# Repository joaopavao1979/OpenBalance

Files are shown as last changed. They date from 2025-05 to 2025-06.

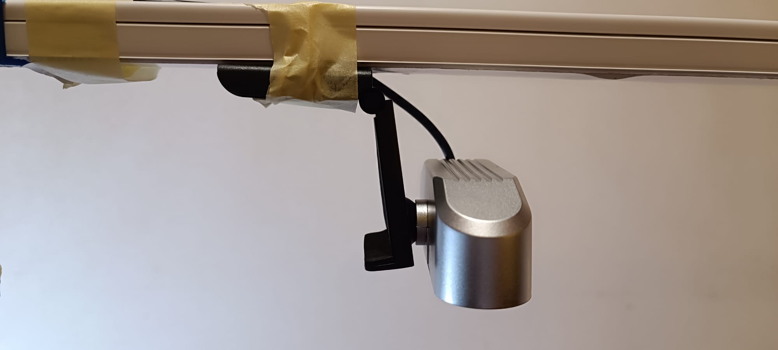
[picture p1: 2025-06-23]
02_estrutura_fisica/fotos_componentes/Eletronica_8.jpg

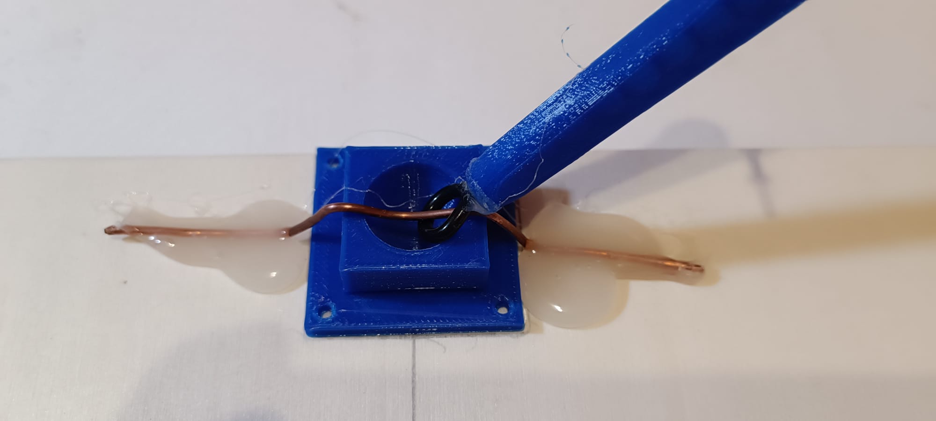
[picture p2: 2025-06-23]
02_estrutura_fisica/fotos_componentes/Estrutura_12.jpg

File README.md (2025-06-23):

# 🧠 OpenBalance – Plataforma de Equilíbrio de Bola com PID

**OpenBalance** é um projeto open source que combina visão computacional, controlo automático com Arduino e estrutura física para explorar conceitos de robótica, inteligência artificial e sistemas dinâmicos.

Desenvolvido no âmbito da pós-graduação **PRIA – Programação, Robótica e Inteligência Artificial**, o projeto tem uma forte componente pedagógica e modular, adaptável para ensino e investigação.

---

## 📂 Estrutura Principal do Projeto

| Pasta | Conteúdo |
|---|---|
| `01_documentacao` | Planeamento, cronogramas, notas e relatórios técnicos |
| `02_estrutura_fisica` | Lista de componentes, montagem física, modelos 3D |
| `03_software_arduino` | Código PID no Arduino, testes, firmware e calibração de servos |
| `04_Dashboard_OpenBalance` | Interface Python com OpenCV, sliders HSV, controlo serial e gráfico PID  |
| `05_testes_e_calibracoes` | Logs, experiências com PID (ex. Ziegler–Nichols), trajetória da bola |
| `06_recursos_pedagogicos` | Guias, fichas de aula, material didático complementar |
| `07_apresentacao` | Slides, posters e ficheiros para comunicação e defesa do projeto |
| `08_artigo_cientifico` | Artigo académico com dados, gráficos e revisão teórica |
| `09_site_github_pages` | Estrutura do site estático para publicação no GitHub Pages |

---

## 🛠️ Tecnologias Utilizadas

- **Arduino UNO** + driver **PCA9685**  
- **Servos DM996R** (13kg)  
- **Python 3.10+**  
- **CustomTkinter**, **OpenCV**, **Matplotlib**, **PySerial**, **NumPy**, **Pillow**

Instalação recomendada:

```bash
pip install customtkinter opencv-python pyserial matplotlib numpy Pillow
```

---

## 📚 Aplicações

- Ensino de sistemas de controlo e PID
- Introdução a visão computacional (HSV, deteção por cor)
- Experiências com IA e reinforcement learning
- Demonstrações práticas em sala de aula

---

## 📄 Licença

- **Código:** [MIT License](LICENSE)  
- **Conteúdos educativos:** [CC BY-NC-SA 4.0](https://creativecommons.org/licenses/by-nc-sa/4.0/)

---

## 👨‍🏫 Desenvolvido por

João Pavão – Universidade dos Açores, Pós-Graduação PRIA  
Com apoio e revisão técnica da equipa docente

---

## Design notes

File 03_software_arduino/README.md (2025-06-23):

# 📁 03_software_arduino

# 💾 Código Arduino – Projeto OpenBalance

Este repositório documenta os diferentes estágios de desenvolvimento do sistema físico OpenBalance, focado no controlo de uma plataforma de equilíbrio de bola com servomotores de alto torque e controlo PID.

O projeto evoluiu ao longo de várias abordagens e testes. Abaixo estão descritas as principais pastas e o papel de cada uma.

---

## 🗂️ Estrutura de Pastas

### 📁 `teste_motores/`
**Objetivo:** Calibração e teste individual dos servos antes da montagem do sistema.  
**Conteúdo:**  
- `calibracao_servos_v1.ino`: permite ajustar manualmente os ângulos dos servos X e Y via monitor série.  
- Comandos como `X80`, `Y120` permitem verificar os limites físicos de forma segura.

---

### 📁 `OpenBalance_Arduino_PID_testes/`
**Objetivo:** Primeiros esboços do controlo PID a correr diretamente no Arduino.  
**Conteúdo:**  
- Testes com controlo PID simples sem integração total com visão computacional.  
- Experiências com filtragem, mapeamento de ângulos e resposta dos motores.

---

### 📁 `OpenBalance_Arduino_Firmware/`
**Objetivo:** Tentativa experimental de mover o cálculo PID para o Python (dashboard), deixando o Arduino apenas a aplicar ângulos.  
**Estado:** Abordagem parcialmente funcional, mas abandonada por instabilidade na comunicação serial e atrasos.  
**Lições aprendidas:** O controlo PID é mais fiável se executado diretamente no microcontrolador.

---

### 📁 `OpenBalance_Arduino_PID/` ✅ **VERSÃO FINAL**
**Objetivo:** Implementação final e estável do sistema com controlo PID on-board.  
**Conteúdo:**  
- `OpenBalance_Arduino_PID.ino`: versão oficial final.  
- O Arduino recebe apenas os erros (X, Y) da dashboard Python via serial e calcula os ângulos de inclinação localmente usando PID.  
- Código comentado, modular e robusto.

---

## ⚙️ Hardware Utilizado

- Arduino UNO ou compatível  
- 2x servos DM996R (15 kg/cm)  
- Driver PCA9685 (PWM 16 canais)  
- Fonte regulável 6V/72W  
- Conexão com PC via USB  

---

## 🔌 Comunicação com Python

- A dashboard em Python envia erros `E,errX,errY` via porta serial.
- Comandos adicionais como `M1` e `M0` ligam/desligam os motores.
- O Arduino responde com mensagens de estado como `MOTORS_ON`.

---

## 🛠️ Bibliotecas Requeridas

- `Wire.h`  
- `Adafruit_PWMServoDriver.h`  

---

## 📌 Notas Finais

- Este repositório serve também fins pedagógicos, sendo documentado e modular.  
- A versão final (pasta `OpenBalance_Arduino_PID/`) deve ser usada como referência para integrações futuras com IA ou reforço (Q-Learning, etc.).

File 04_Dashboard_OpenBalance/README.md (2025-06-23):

# 📁 04_Dashboard_OpenBalance

# 🖥️ Dashboard Python – Projeto OpenBalance

Este repositório contém o código da interface gráfica desenvolvida em Python para o sistema físico OpenBalance, que controla uma plataforma de equilíbrio de bola em tempo real. Utiliza visão computacional, controlo PID e comunicação serial com Arduino.

---

## 🗂️ Estrutura de Pastas

### 📁 `testes_Dashboard/`
**Objetivo:** Reunião de versões experimentais e esboços da interface.  
**Conteúdo:**  
- Primeiros testes com Tkinter, sliders HSV, deteção OpenCV, e comunicação serial.  
- Algumas versões antigas ou auxiliares podem ser limpas futuramente.

---

### 📁 `Dashboard_estável/`
**Objetivo:** Versão funcional e confiável da dashboard sem gráfico de erros.  
**Características:**  
- Envio de erros `E,errX,errY` via serial.  
- Interface modular com sliders HSV, centro clicável, e controlo de motores.  
- Estável e ideal para execução contínua sem sobrecarga gráfica.

---

### 📁 `Dashboard_OpenBalance_V1.0/` ✅ **VERSÃO FINAL**
**Objetivo:** Versão final da interface com **gráfico de erro X/Y em tempo real**.  
**Ficheiro principal:** `Dashboard_OpenBalance_V1.0.py`  
**Conteúdo:**  
- Visualização OpenCV (320x240) com sobreposição de posição da bola e centro de referência.  
- Sliders ajustáveis HSV para calibração visual.  
- Controlo serial completo com comandos `M1`, `M0`, e `E,errX,errY`.  
- Interface robusta com secção para PID, estado, nivelamento e modo de seguimento.  
- Integração com `matplotlib` para abrir janela com gráfico de erro acumulado ao clicar no botão correspondente.

---

## 📦 Bibliotecas Usadas

- `customtkinter`  
- `opencv-python` (`cv2`)  
- `pyserial`  
- `Pillow`  
- `numpy`  
- `matplotlib`

Instalação recomendada:

```bash
pip install customtkinter opencv-python pyserial Pillow numpy matplotlib
```

---

## 🔌 Comunicação com Arduino

- Envio de erros via porta serial no formato: `E,errX,errY`
- Comandos de controlo:  
  - `M1` → Ativa motores  
  - `M0` → Desativa motores  
- Sincronização total com o firmware `OpenBalance_Arduino_PID.ino`

---

## 📌 Notas Finais

- A versão **`Dashboard_OpenBalance_V1.0`** deve ser usada para demonstrações e testes finais.  
- A pasta `Dashboard_estável` mantém uma alternativa leve e funcional, sem gráfico.
- As versões em `testes_Dashboard` são experimentais e poderão ser organizadas ou removidas.

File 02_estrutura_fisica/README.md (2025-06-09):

# 📁 02_estrutura_fisica

Modelos 3D (.STL e .FCStd), plantas, esquemas da estrutura da calha ou plataforma, fotos da montagem e ideias de design.

## 📦 Conteúdo

### 📁 STL/
Modelos 3D prontos para impressão:

### 📁 OBJ/
Modelos 3D 

### 📁 desenhos_tecnicos/
- Esquemas técnicos em PDF e PNG com cotas e vistas laterais
- Ideal para revisão ou produção manual

### 📁 fotos_componentes/
- Fotografias tiradas durante o processo de montagem aos componentes usados no projeto
- Ajuda visual passo a passo

### 📁 fotos_montagem/
- Fotografias tiradas durante o processo de montagem aos componentes usados no projeto
- Ajuda visual passo a passo

---

## 📋 Lista de Materiais (BOM)

| Componente | Qt. | Observações |
|---|-----|---|
| Servos MG996R | 2 | Alto torque, 180° |
| Parafuso M4x16 | 6 | Para articulações dos braços |
| Porca M4 com travamento | 6 | Evita folgas |
| Cabo jumper (M-M) | 20  | Para ligação ao Arduino |
| Base em MDF 30x42 cm | 2  | Com furações para os servos |

---

## 🪛 Instruções de Montagem

1. Imprimir os braços superior e inferior (x2 de cada)
2. Montar cada conjunto com um servo MG996R e um parafuso M4
3. Fixar os servos à base (usar `base_madeira_furos.pdf`)
4. Apoiar a plataforma sobre as 3 esferas
5. Verificar se a inclinação ocorre suavemente

---

## 🖨️ Recomendações de Impressão

- Material: PLA ou PETG
- Altura de camada: 0.2 mm
- Preenchimento: ≥30%
- Suportes: apenas se necessário nas juntas

---

## ✍️ Contribuições

Se quiseres propor melhorias nos modelos STL ou na montagem física, envia um pull request ou abre uma issue no repositório principal.

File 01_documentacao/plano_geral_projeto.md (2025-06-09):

# 🧠 Plano Geral do Projeto – OpenBalance

**Nome do Projeto:** OpenBalance  
**Autor:** João Pavão  
**Instituição:** Universidade dos Açores – PRIA  
**Período:** de maio a junho 2025  
**Versão:** 1.0

---

## 🎯 Objetivo Geral

Desenvolver um sistema open source capaz de manter uma bola em equilíbrio sobre uma plataforma inclinável, através de controlo PID e deteção da posição via visão computacional. O projeto visa integrar conhecimentos de eletrónica, programação, robótica e física, com aplicação pedagógica e científica.

---

## 📦 Componentes principais

| Componente | Função |
|---|---|
| Arduino (ex: UNO ou Leonardo) | Controlo dos servos e receção de comandos |
| 2 Servos Motores (eixo X e Y) | Ajuste da inclinação da plataforma |
| Estrutura 3D (braços + prato) | Suporte físico articulado |
| Webcam + OpenCV | Deteção da posição da bola em tempo real  |
| Python | Cálculo do PID e interface com Arduino |

---

## 🛠️ Etapas do Projeto

1. Impressão 3D e montagem dos braços articulados
2. Controlo manual dos servos via Arduino
3. Integração com PID em Python
4. Implementação de visão computacional com OpenCV
5. Criação de interface gráfica para ajuste dos parâmetros
6. Testes e calibração da resposta
7. Documentação técnica e pedagógica
8. Entrega final com vídeo, artigo e relatório

---

## 🎓 Aplicação pedagógica

O OpenBalance será usado como ferramenta de aprendizagem interdisciplinar:
- Física: sistemas de controlo, equilíbrio, movimento
- Matemática: funções PID, ângulos, vetores
- Programação: comunicação serial, tratamento de imagem
- Engenharia: design e montagem de estruturas móveis

---

## 🔓 Licenciamento

- **Código-fonte:** Licença MIT  
- **Modelos 3D, tutoriais e vídeos:** Creative Commons BY-NC-SA 4.0  

---

## 🔗 Repositórios e ligações

- GitHub do projeto: `https://github.com/joaopavao/openbalance`
- GitHub Pages (site): `https://joaopavao.github.io/openbalance`
- Pasta com ficheiros STL e documentação: `02_hardware/` e `01_documentacao/`

---

## 📝 Atualizações

- `27/05/2025`: Criação do projeto e estrutura de pastas
- `01/06/2025`: Início da montagem física
- `08/06/2025`: Finalização da construção da plataforma
- (continua...)

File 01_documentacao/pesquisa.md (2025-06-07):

# 🔍 Pesquisa Técnica – Projeto OpenBalance

**Objetivo:**  
Pesquisa inicial para o desenvolvimento de um projeto open source de **plataforma equilibradora de bola com controlo PID**, integrando eletrónica, impressão 3D e visão computacional.

---

## 🧠 Inspirações no GitHub

### 🔗 JohanLink – Ball-Balancing-PID-System
- Repositório: [https://github.com/JohanLink/Ball-Balancing-PID-System](https://github.com/JohanLink/Ball-Balancing-PID-System)
- Projeto muito bem documentado, com:
  - Visão computacional com OpenCV
  - PID controlado via Python
  - Montagem física com braços articulados
- **Referência principal para o OpenBalance**

---

### 🔗 giusenso – Ball-Balancing-PID-System
- Repositório: [https://github.com/giusenso/Ball-Balancing-PID-System](https://github.com/giusenso/Ball-Balancing-PID-System)
- Projeto alternativo com abordagem semelhante
- Útil para comparar diferentes estratégias de controlo

---

## 🧩 Modelos no Thingiverse

### 🎲 Johan Link – Ball Balancing PID System
- Projeto também publicado no Thingiverse
- Inclui ficheiros STL para braços articulados
- Impressão 3D simples, adaptável

### 🤖 BaBot – The Ball Balancing Robot (possível variação)
- Nome encontrado durante a pesquisa, necessita verificação
- Pode ser uma versão robótica com PID + rodas

---

## 📁 Notas e próximos passos

- Escolher o modelo mais simples para iniciar testes (3 DoF)
- Confirmar o uso de esfera metálica de 10 mm
- Definir os limites de rotação e altura da plataforma
- Documentar todos os testes no `diario_bordo.md`

---

## 🔗 Recursos adicionais a explorar

- Artigos científicos sobre controlo PID com Arduino
- Plataformas Stewart 3D (para versão futura com 6 DoF)
- Alternativas como HuskyLens para visão embarcada
- Projetos da comunidade OpenCV com detecção de objetos coloridos

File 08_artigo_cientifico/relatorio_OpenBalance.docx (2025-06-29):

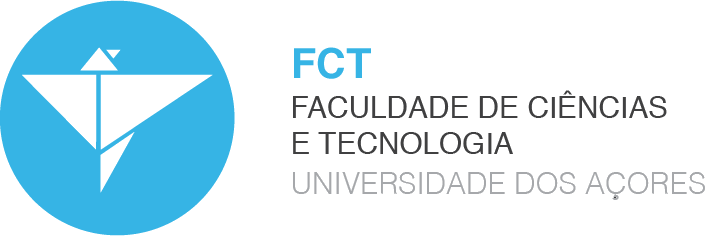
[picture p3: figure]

FACULDADE DE CIÊNCIAS E TECNOLOGIA DA UNIVERSIDADE DOS AÇORES -

CAMPUS de Ponta Delgada

COORDENAÇÃO DE CURSO DE PÓS-GRADUAÇÃO EM PROGRAMAÇÃO, ROBÓTICA E INTELIGÊNCIA ARTIFICIAL

Laboratório de Aplicações em Robótica e Aprendizagem

OpenBalance

Plataforma de Equilíbrio com Visão Computacional e Controlo PID

João Pavão

FCT – UAC

Ponta Delgada, 23 de junho de 2025

João Pavão

OpenBalance

Plataforma de Equilíbrio com Visão Computacional e Controlo PID

Relatório de atividade laboratorial para avaliação de disciplina Laboratório de Aplicações em Robótica e Aprendizagem sob orientação do Prof. José Cascalho.

FCT – UAC

Ponta Delgada, 23 de junho de 2025

RESUMO

Este relatório apresenta o desenvolvimento do projeto OpenBalance, uma plataforma robótica experimental concebida para equilibrar uma bola em tempo real, controlando dinamicamente a inclinação da sua superfície. O sistema recorre a visão computacional (OpenCV) para detetar a posição da bola e aplica algoritmos de controlo PID para mantê-la centrada. Desenvolvido no contexto da unidade curricular de Laboratório de Aplicações em Robótica e Aprendizagem (PRIA), o projeto integra conhecimentos de mecânica, eletrónica, automação e inteligência artificial aplicada. A estrutura física é composta por componentes impressos em 3D, articulações mecânicas e suportes que garantem graus de liberdade bem definidos. No domínio da eletrónica, são utilizados servomotores de alto torque, um driver PCA9685, um Arduino UNO e uma fonte de alimentação estabilizada. A deteção visual e o controlo são integrados numa interface gráfica interativa em Python, desenvolvida com CustomTkinter. Os testes realizados demonstraram estabilidade, resposta eficiente ao controlo e elevado potencial educativo, validando a proposta como recurso didático modular e reprodutível.

Palavras-chave: Visão Computacional, Controlo PID, Arduino, Mecatrónica, Interface Gráfica, Plataforma de Equilíbrio, Python

ABSTRACT

This report presents the development of OpenBalance, an experimental robotic platform designed to balance a ball in real time by dynamically controlling the inclination of its surface. The system uses computer vision (OpenCV) to detect the ball's position and applies PID control algorithms to recenter it continuously. Developed within the scope of the Laboratory of Robotics and Learning Applications (PRIA) course, the project integrates knowledge from mechanics, electronics, automation, and applied artificial intelligence. The physical structure consists of 3D-printed components, mechanical joints, and supports that define specific degrees of freedom. On the electronics side, the system uses high-torque servomotors, a PCA9685 servo driver, an Arduino UNO, and a regulated power supply. Visual detection and control are managed through an interactive graphical interface in Python, built with CustomTkinter. The conducted tests demonstrated system stability, effective response to control inputs, and strong educational potential, validating the platform as a modular and reproducible teaching tool.

Keywords: Computer Vision, PID Control, Arduino, Mechatronics, Graphical Interface, Ball-Balancing Platform, Python

1 INTRODUÇÃO

O projeto OpenBalance foi desenvolvido no contexto da unidade curricular de Laboratório de Aplicações em Robótica e Aprendizagem (PRIA), com o objetivo de demonstrar, de forma prática e interativa, os princípios do controlo automático aplicados ao equilíbrio de uma bola sobre uma superfície inclinável.

A plataforma física, com dois graus de liberdade (eixos X e Y), utiliza servomotores de alto torque controlados por um Arduino UNO e um driver PCA9685. A posição da bola é detetada em tempo real por uma webcam USB, com processamento de imagem em Python (OpenCV). Os ângulos de inclinação são definidos por um controlador PID, com parâmetros ajustáveis por uma interface gráfica desenvolvida em CustomTkinter.

Concebido com foco pedagógico e modularidade, o OpenBalance visa facilitar o ensino de robótica, visão computacional e controlo, permitindo ainda perspetivar evoluções futuras com inteligência artificial aplicada.

2 OBJETIVO

O objetivo principal do projeto é desenvolver uma plataforma robótica educativa que permita explorar conceitos de controlo PID e visão computacional em tempo real, num sistema físico acessível e reprodutível.

Objetivos específicos:

- Construir uma plataforma mecânica com dois eixos de inclinação (X/Y);
- Detetar a posição da bola por webcam e OpenCV;
- Aplicar controlo PID para manter a bola centrada;
- Desenvolver uma interface gráfica com ajuste HSV e controlo PID;
- Calibrar o sistema e otimizar o desempenho;
- Documentar o projeto e disponibilizá-lo em repositório open source;
- Explorar expansões futuras: controlo com mais atuadores, plataforma tipo Stewart, RL e sensores táteis.
3 CONTEXTO

Inserido no curso de pós-graduação em Programação, Robótica e Inteligência Artificial (PRIA), o OpenBalance é uma plataforma didática que conjuga hardware acessível e software livre para demonstrar, em tempo real, o funcionamento de sistemas de controlo. O sistema integra uma base física inclinável (PLA+contraplacado), dois servomotores DM996, um Arduino UNO com driver PCA9685 e uma webcam. A deteção da bola é feita por segmentação de cor via OpenCV, e o controlo é realizado por algoritmos PID com comunicação serial entre Python e Arduino. A interface gráfica permite controlar o sistema e ajustar parâmetros de forma intuitiva. Este projeto promove a aprendizagem prática de conceitos de robótica e automação, sendo facilmente replicável em ambientes educativos com recursos limitados.

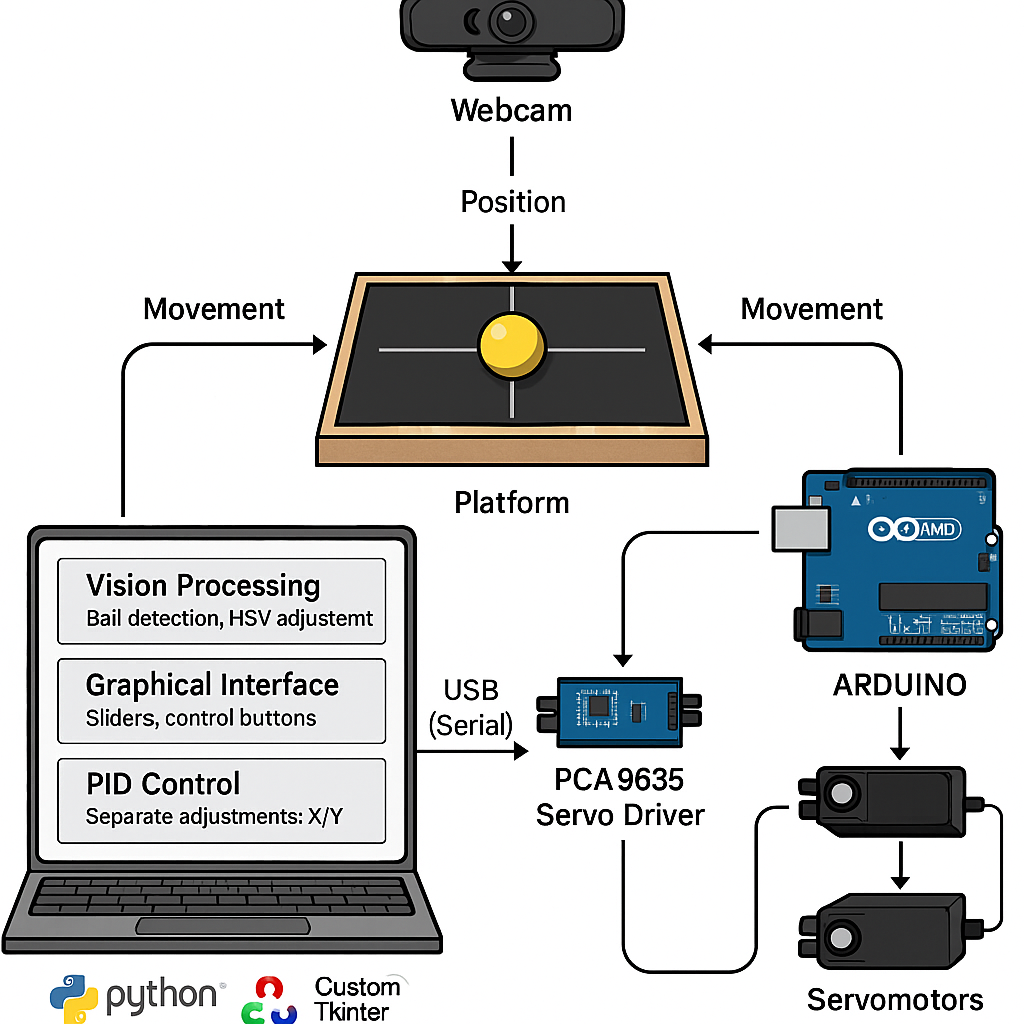
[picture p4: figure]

Figura 1 – Diagrama de arquitetura do sistema OpenBalance

4 DESENVOLVIMENTO E RESULTADOS

O projeto OpenBalance foi desenvolvido em várias fases, desde a montagem física até à implementação dos sistemas de controlo e interface. A plataforma seguiu princípios de modularidade, acessibilidade e reprodutibilidade, com recurso a componentes simples e ferramentas open source.

Estrutura física e montagem

A estrutura foi construída com base móvel em contraplacado leve e suportes articulados em PLA. Dois servomotores DM996 (15 kg·cm) montados lateralmente permitem controlar a inclinação nos eixos X e Y. A plataforma assenta sobre um pivô côncavo, garantindo estabilidade e liberdade de movimento. Encaixes tipo cavilha nos braços asseguram o alinhamento e evitam deslizamento.

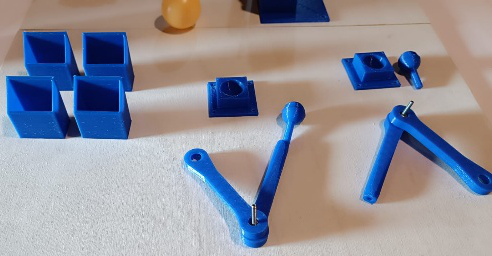
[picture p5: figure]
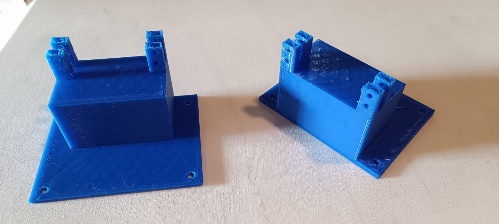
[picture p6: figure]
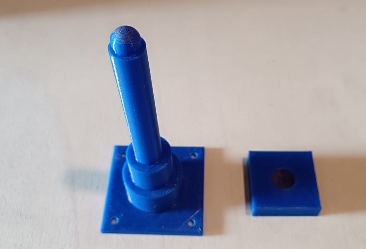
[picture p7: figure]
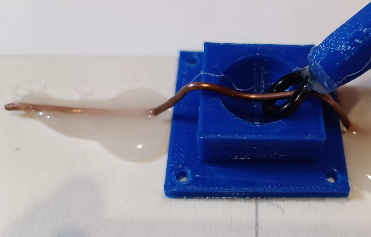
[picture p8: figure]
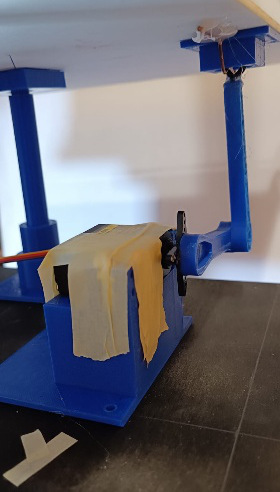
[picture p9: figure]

Figura 2 – Vários componentes que formam a estrutura da plataforma

A superfície visível da plataforma foi pintada de preto com uma cruz central (destinada ao alinhamento da webcam e a plataforma) e uma borda de madeira natural (~4 mm), otimizando o contraste visual para a deteção por visão computacional.

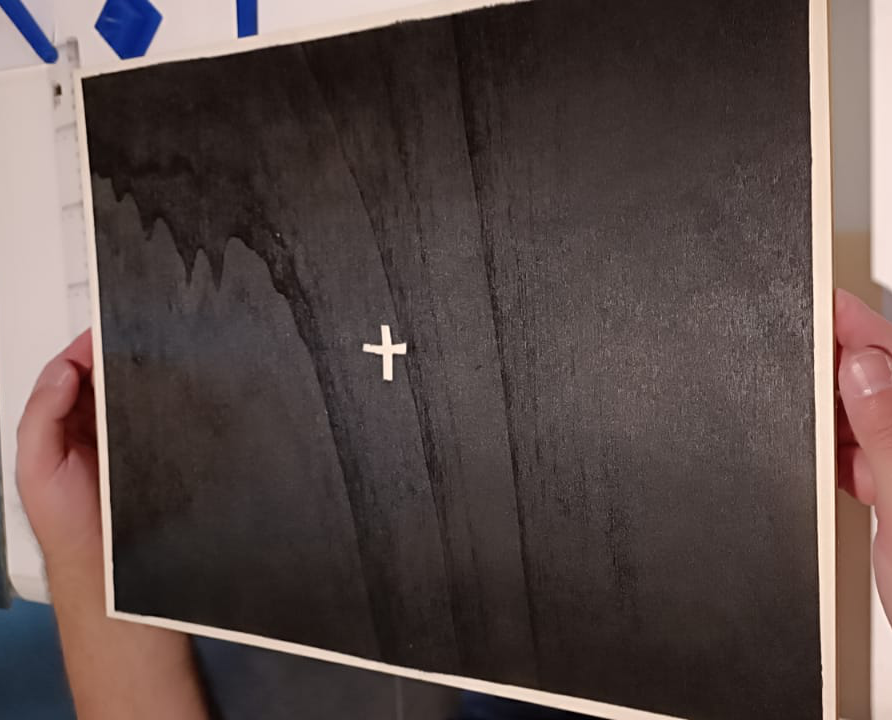
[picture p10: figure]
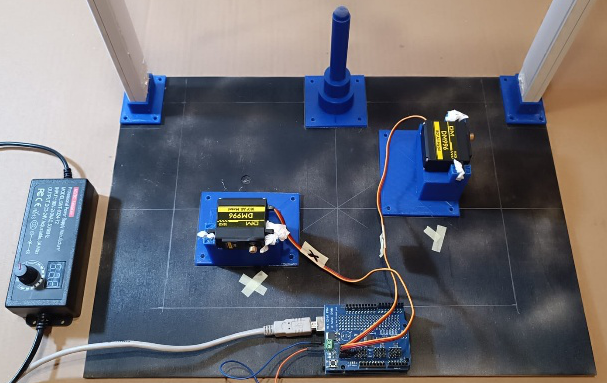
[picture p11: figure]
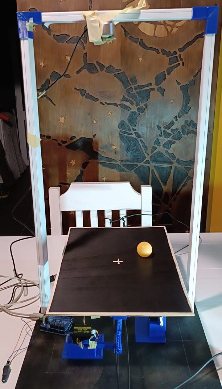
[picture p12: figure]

Figura 3 – Montagem da estrutura – etapas finais

Sistema eletrónico

O controlo dos servos é feito por um Arduino UNO ligado a um driver PCA9685 (I²C), que gera sinais PWM precisos. A alimentação é fornecida por uma fonte regulável de 6 V / 72 W, isolando o Arduino da carga. A comunicação com o PC é realizada via porta serial USB. A deteção da bola é feita por uma webcam USB montada verticalmente sobre a plataforma.

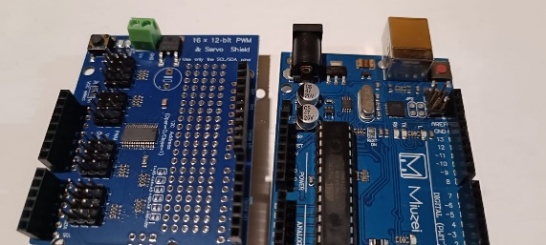
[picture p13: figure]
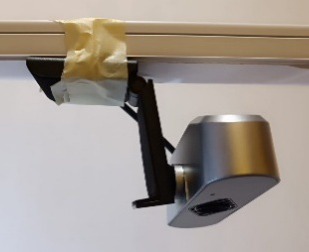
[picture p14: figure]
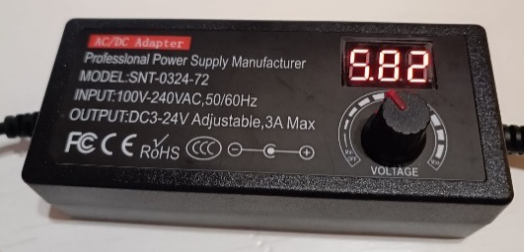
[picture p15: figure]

Driver PCA9685 e Arduino Uno | Webcam USB | Fonte regulável

Figura 4 – Vários componentes da parte eletrónica

Calibração dos servomotores

Para garantir movimentos seguros e previsíveis, foi realizada calibração manual dos servos. Cada motor foi centrado a 90°, alinhando a estrutura para obter uma superfície nivelada. Utilizando um sketch de teste, determinaram-se os limites operacionais:

• Eixo X: 80°–120°

• Eixo Y: 70°–110°

Estes valores foram inseridos no firmware, assegurando que os comandos respeitam os limites físicos.

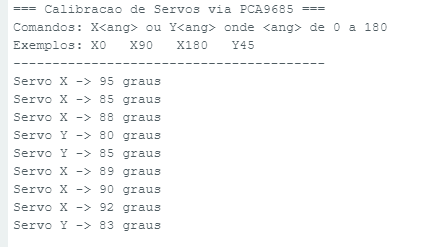
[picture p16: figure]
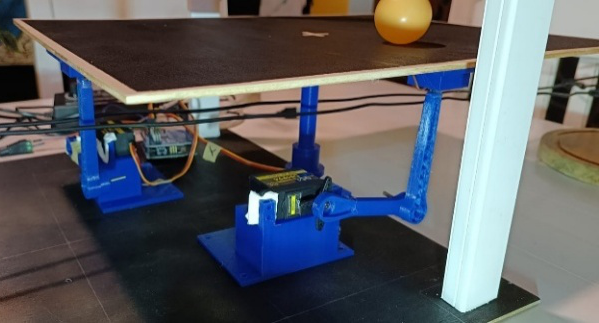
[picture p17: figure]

Calibração dos motores feita no monitor serial do Arduino IDE | Calibração dos motores de modo a permitir a plataforma nivelada

Figura 4 – Calibração manual dos servomotores

Sintonização PID com o Método de Ziegler–Nichols

A afinação do controlo PID requer definição adequada dos ganhos proporcional (Kp), integral (Ki) e derivativo (Kd). Uma abordagem empírica eficaz, mesmo sem modelo matemático, é o método de Ziegler–Nichols (ZN), amplamente utilizado.

O procedimento consiste em:

1. Desativar Ki e Kd;
2. Aumentar Kp até provocar oscilações sustentadas (→ obter Ku);
3. Medir o período de oscilação (Tu);
4. Aplicar as fórmulas empíricas para calcular os ganhos ótimos.

Tabela 1 – Fórmulas empíricas de sintonização segundo Ziegler–Nichols

Tipo de controlador | Kp | Ki | Kd
P | 0.50 × Ku | — | —
PI | 0.45 × Ku | 1.2 × Kp / Tu | —
PID | 0.60 × Ku | 2 × Kp / Tu | Kp × Tu / 8

Foram realizados testes variando Kp no eixo X, com Ki e Kd a zero e o eixo Y desativado. A análise do comportamento permitiu avaliar a sensibilidade do sistema ao ganho proporcional e orientar a introdução progressiva de Ki e Kd, com base em tentativa e erro.

Tabela 2 – Testes experimentais de controlo proporcional no eixo X

Após a afinação individual dos eixos, o controlo PID foi ativado simultaneamente. Os valores atualmente utilizados no firmware estão ilustrados na Figura 5 e servem como referência inicial, podendo ser ajustados conforme a resposta do sistema.

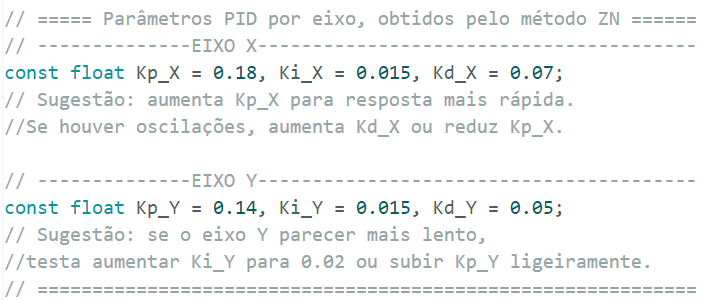
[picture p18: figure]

Figura 5 - Parâmetros PID definidos no firmware Arduino com base no método ZN

Está prevista uma futura atualização da dashboard com funcionalidade ZN, que estimará automaticamente os ganhos PID a partir do comportamento oscilatório, simplificando e acelerando o processo de afinação.

Interface gráfica e interatividade

A interface gráfica foi desenvolvida em CustomTkinter, com arquitetura modular e tema escuro. É composta por três áreas principais:

- Painel HSV – sliders para ajuste em tempo real da segmentação por cor, com presets e visualização da máscara;
- Área de vídeo – exibe a imagem processada com a bola detetada, erro X/Y e marcadores de referência;
- Controlo do sistema – botões para gerir motores, seguimento automático, redefinir o centro e escolher a porta COM.

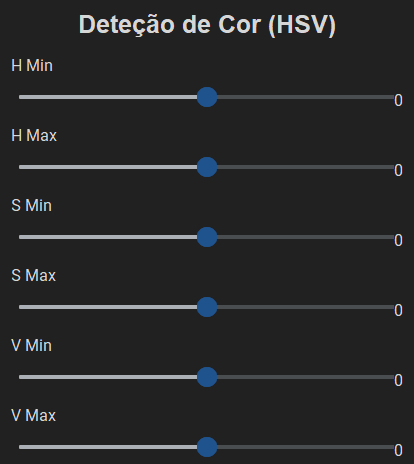
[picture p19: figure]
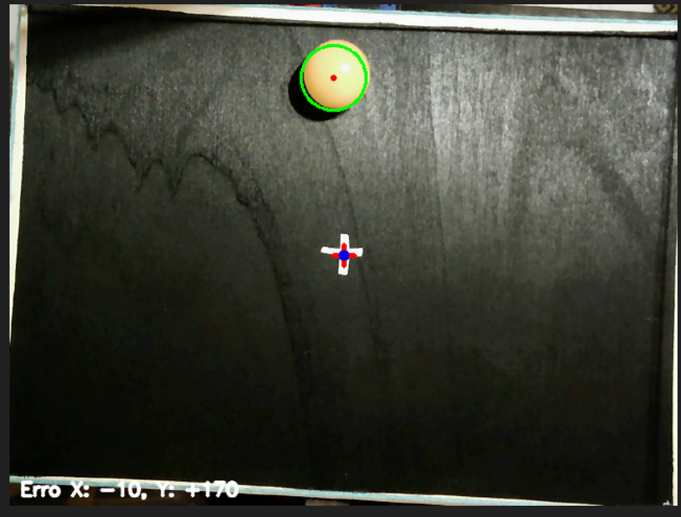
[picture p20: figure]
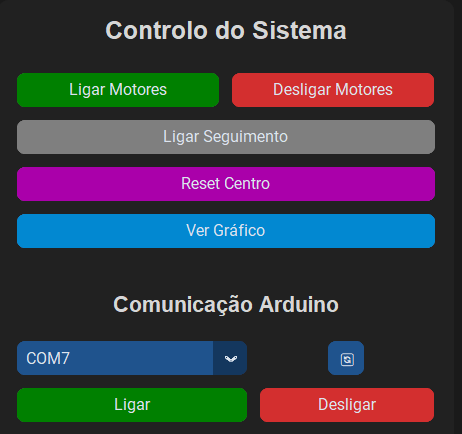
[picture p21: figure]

Painel HSV | Área de Visualização | Controlo do Sistema

Figura 6 – Várias partes constituintes da interface gráfica

A versão 1.0 da dashboard inclui:

• Janela popup com gráficos em tempo real (Erro X/Y vs Tempo e Trajetória Y vs X);

• Resolução de vídeo 640×480, equilibrando qualidade e desempenho;

• Barra de estado com mensagens de sistema e erros;

• Botão "Reset Centro", que redefine visualmente o ponto de convergência da bola com um clique, facilitando os testes.

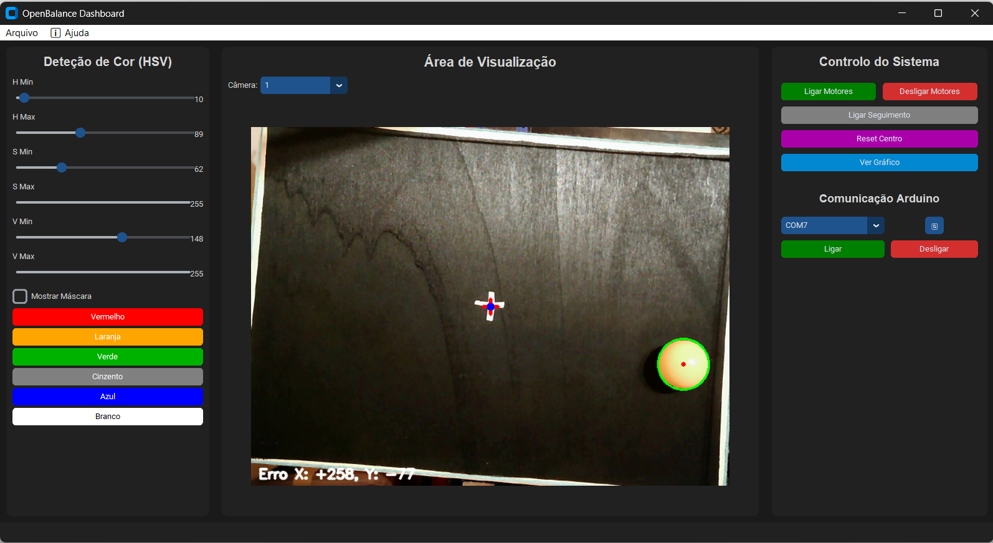
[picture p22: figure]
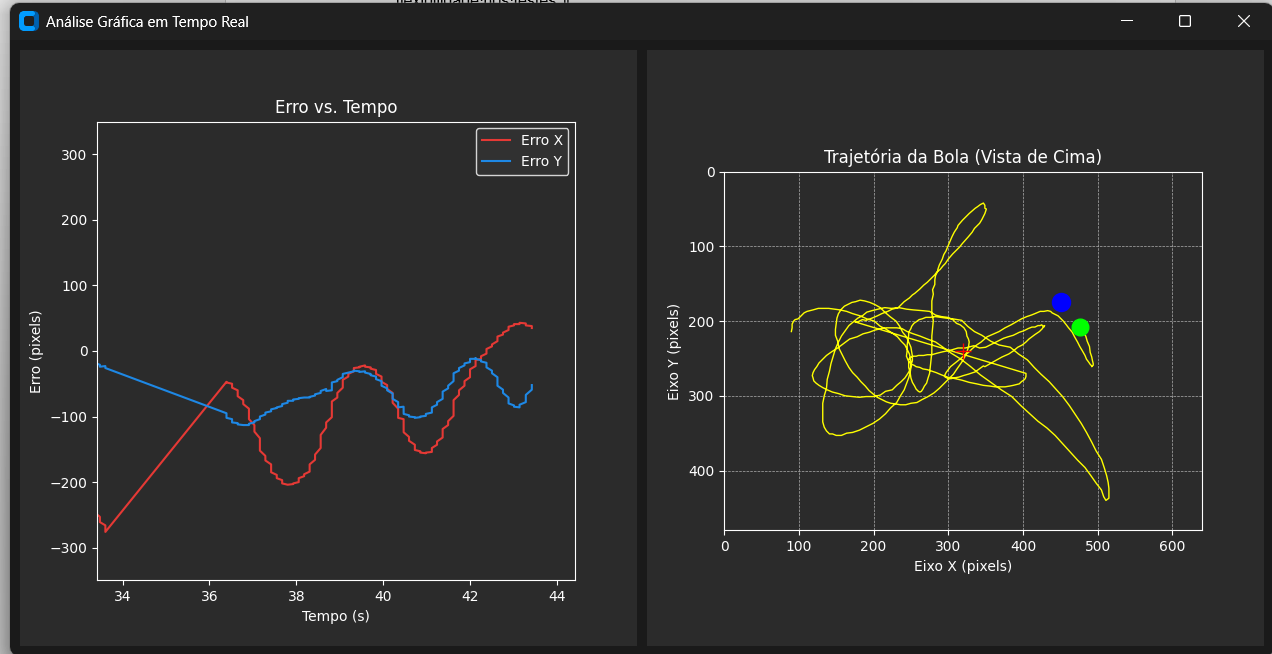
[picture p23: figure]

Figura 7 - Interface gráfica da dashboard OpenBalance (v1.0) e Análise gráfica em tempo real

A aplicação permite guardar/carregar configurações HSV (JSON), alternar entre câmaras e aceder a menus de ajuda. Foi concebida como ferramenta robusta, pedagógica e extensível para afinação e demonstrações educativas.

Testes e resultados preliminares

Os testes realizados em ambiente real revelaram:

• Deteção visual eficaz com bolas contrastantes (ex: laranja), a 20–25 FPS sob luz difusa;

• Estabilização confiável após perturbações, com PID ajustado por Ziegler–Nichols;

• Resposta física precisa dos servos, com limites que evitam colisões;

• Afinação assistida, facilitada pela visualização em tempo real dos efeitos dos parâmetros.

O projeto está documentado num repositório GitHub com vídeos, presets e imagens:

https://github.com/joaopavao1979/OpenBalance

Procedimento futuro para Aplicação de Algoritmos de Otimização e Aprendizagem

Para integrar algoritmos de otimização e aprendizagem no OpenBalance, propõe-se um procedimento experimental com aplicação direta no sistema físico, útil para afinar controladores PID ou treinar agentes de Reinforcement Learning (RL) com base em dados reais.

1. Definir parâmetros e intervalos:

Selecionar os parâmetros a otimizar (ex: Kp, Ki, Kd ou políticas de ação), definindo limites seguros.

2. Preparar o sistema:

Garantir estabilidade e segurança (ex: proteção contra quedas). A comunicação Arduino–Python deve aceitar envio dinâmico de parâmetros, com visão ativa.

3. Estruturar episódios experimentais:

Cada episódio inclui:

- Envio de parâmetros;
- Execução por tempo fixo ou até falha;
- Cálculo de métricas (erro, tempo até falha, número de colisões);
- Armazenamento dos dados.

4. Critérios de término:

Encerrar o episódio ao detetar colisão ou atingir o tempo-limite.

5. Aplicar o algoritmo:

Possíveis abordagens:

- Hill Climbing – variações incrementais com seleção por desempenho;
- Q-Learning – construção de política discreta com base em recompensas;
- Outros …

6. Registo e visualização:

Guardar os resultados e gerar gráficos de evolução e comparação de estratégias.

7. Validação final:

Testar a solução considerada ótima em vários episódios para avaliar robustez e consistência. Este procedimento fornece uma base sólida para aplicação de algoritmos de controlo inteligente em robótica, permitindo explorar IA de forma prática.

5 CONCLUSÃO

O projeto OpenBalance permitiu aplicar, de forma prática e integrada, os conhecimentos adquiridos na unidade curricular de Laboratório de Aplicações em Robótica e Aprendizagem (PRIA). Através da construção de uma plataforma física capaz de equilibrar uma bola com base em visão computacional e controlo PID, foram explorados conceitos fundamentais de automação, eletrónica e programação, perspetivando-se futuramente a integração de inteligência artificial aplicada.

Privilegiando simplicidade, modularidade e reprodutibilidade, a plataforma utilizou componentes acessíveis e software open source. A interface gráfica desenvolvida em Python com OpenCV e CustomTkinter, aliada à comunicação com o Arduino, revelou-se uma solução eficaz para controlo e afinação em tempo real, com clara mais-valia para contextos didáticos.

Do ponto de vista pedagógico, o sistema demonstrou elevado potencial como recurso de ensino em áreas como controlo automático, visão computacional e robótica, favorecendo a aprendizagem ativa e a ligação entre teoria e prática.

No entanto, o projeto enfrentou desafios importantes. A calibração física da plataforma revelou-se mais complexa do que o esperado, sendo difícil realizar a afinação Ziegler–Nichols por eixo e combinar ambos de forma linear. Também surgiram limitações na estrutura mecânica, como a fragilidade dos braços e uniões da plataforma, que exigiram reforços improvisados com cola quente, fita adesiva e ajustes manuais. A montagem exigiu várias tentativas e erros, especialmente ao alinhar os ângulos neutros dos servos.

Apesar destas dificuldades, a experiência foi profundamente formativa, destacando a importância da prototipagem, da integração entre hardware e software e da capacidade de adaptação perante constrangimentos reais. Salienta-se ainda o valor da cultura maker, que deve ser mais promovida nos clubes de robótica, incentivando a experimentação prática, a criatividade e a resolução colaborativa de problemas.

Perspetivas Futuras

A experiência adquirida com o OpenBalance abre várias possibilidades de evolução:

• Expansão para sistemas com mais graus de liberdade;

• Inclusão de braços articulados capazes de interagir ativamente com a bola, promovendo comportamentos orientados a objetivos;

• Integração de algoritmos de aprendizagem por reforço, permitindo adaptação progressiva baseada na experiência;

• Substituição da visão computacional por superfícies táteis ou resistivas, melhorando a latência e fiabilidade da deteção;

• Uso de câmaras de maior resolução e processamento embarcado com Raspberry Pi, aumentando a autonomia e portabilidade.

A nível pessoal e académico, o projeto reforçou a importância da experimentação, da integração entre hardware e software e do potencial das ferramentas open source em contextos educativos. No futuro, pretendo continuar a explorar formas de tornar sistemas como o OpenBalance mais autónomos, interativos e adaptativos, integrando aprendizagem automática e novas modalidades sensoriais.

BIBLIOGRAFIA

### Referências Bibliográficas – Artigos Científicos

- Pradeepa, S. C., Abhijith, N., Amoghavarsha, S. G., Kiran, C. N., & Niranjana Jois, H. C. (2022). Ball balancing PID system using image processing. International Journal for Research in Applied Science & Engineering Technology (IJRASET), 10(VIII), 397–406. https://doi.org/10.22214/ijraset.2022.46190
- Frank, A. H., & Tjernström, M. (2019). Construction and theoretical study of a ball balancing platform: Limitations when stabilizing dynamic systems through implementation of automatic control theory (Bachelor’s thesis, KTH Royal Institute of Technology). TRITA ITM-EX 2019:35. https://www.kth.se
- Maldonado, A., Bueno, C., Loza, D., & Ibarra, A. (s.d.). Design, construction and implementation of Stewart Platform – Control of rolling ball on platform through artificial vision. Universidad de las Fuerzas Armadas – ESPE.
- Ziegler, J. G., & Nichols, N. B. (1942). Optimum settings for automatic controllers. Transactions of the ASME, 64, 759–768. Disponível em http://www.driedger.ca

Controlo e Automação

- Ogata, K. (2010). Modern Control Engineering (5th ed.). Prentice Hall.
- Dorf, R. C., & Bishop, R. H. (2017). Modern Control Systems (13th ed.). Pearson.
- Nise, N. S. (2020). Control Systems Engineering (8th ed.). Wiley.

Robótica Educacional e Arduino

- Blum, J. (2013). Exploring Arduino: Tools and Techniques for Engineering Wizardry. Wiley.
- Monk, S. (2016). Programming Arduino: Getting Started with Sketches (2nd ed.). McGraw-Hill Education.

Python, OpenCV e Interfaces Gráficas

- Beyeler, M. (2017). Machine Learning for OpenCV. Packt Publishing.
- Laganière, R. (2014). OpenCV 3 Computer Vision Application Programming Cookbook. Packt Publishing.
- Chen, J. (2023). Learn OpenCV with Python by Examples.
- Harrison, M. (2017). Tkinter GUI Programming by Example. Packt Publishing.

Webgrafia

- GitHub – JohanLink:

https://github.com/JohanLink/Ball-Balancing-PID-System

- GitHub – giusenso:

https://github.com/giusenso/Ball-Balancing-PID-System

- Thingiverse – Ball Balancing PID Robot:

https://www.thingiverse.com/thing:4457405

- Documentação oficial do OpenCV:

https://docs.opencv.org

- Adafruit – 16-Channel PWM Servo Driver (PCA9685):

https://learn.adafruit.com/16-channel-pwm-servo-driver

- CustomTkinter – GUI Moderna para Python:

https://github.com/TomSchimansky/CustomTkinter

- Control Engineering – PID Control Explained:

https://www.controleng.com/articles/pid-control-explained

- Maker Guides – Curso de Controlo PID com Arduino:

https://www.makerguides.com/arduino-pid-controller

Utilização de Inteligência Artificial como Ferramenta de Apoio

Durante a elaboração deste projeto, foram utilizadas ferramentas de Inteligência Artificial generativa como ChatGPT (OpenAI), Gemini AI (Google AI Studio) e Grok (xAI), com o objetivo de apoiar a estruturação do relatório, esclarecer dúvidas técnicas e sugerir soluções programáticas. Estas ferramentas serviram como complemento ao trabalho do autor, que foi responsável pela interpretação, implementação e validação prática de todas as soluções propostas.

Exemplos de prompts utilizados:

- “Cria uma estrutura de relatório técnico para um projeto de controlo PID com visão computacional.”
- “Explica como calibrar servos com Arduino usando PCA9685.”
- “Como implementar controlo PID em Python com comunicação serial para Arduino?”
- “Sugere uma interface gráfica com CustomTkinter para controlo PID e HSV em tempo real.”
- “Descreve os passos de testes e validação de um sistema que equilibra uma bola com feedback visual.”
- “Adiciona perspetivas futuras para uma plataforma de controlo com múltiplos braços e IA.”
- “Faz uma reflexão final para relatório técnico com foco pedagógico e open-source.”

Estas interações fazem parte do processo de engenharia de prompts, uma prática recente e relevante na utilização eficaz de sistemas de IA, que foi conscientemente explorada como ferramenta de aprendizagem e prototipagem rápida.

Ferramentas de IA utilizadas:

- ChatGPT – OpenAI:https://chat.openai.com
- Gemini AI Studio – Google:https://studio.google.com
- Grok – xAI:https://x.com

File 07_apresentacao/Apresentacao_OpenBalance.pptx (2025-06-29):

## OpenBalance Plataforma de Equilíbrio com Controlo PID e Visão Computacional

https://github.com/joaopavao1979/OpenBalance
PRIA – Laboratório de Aplicações em Robótica e Aprendizagem
Autor: João Pavão
Data: 27 de junho de 2025

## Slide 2

A IDEIA

Plataforma que equilibra uma bola automaticamente
Usa câmara para detetar a posição da bola
Controla a inclinação com dois servos (X e Y)
Algoritmo PID ajusta os ângulos em tempo real
Projeto educativo e open-source

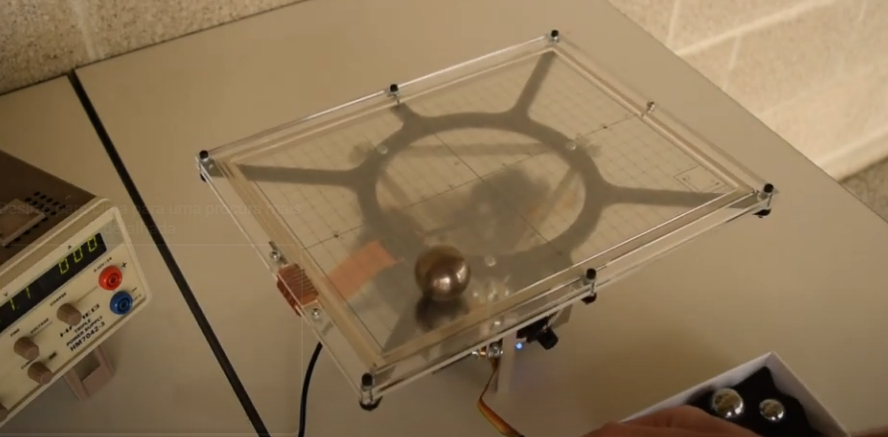
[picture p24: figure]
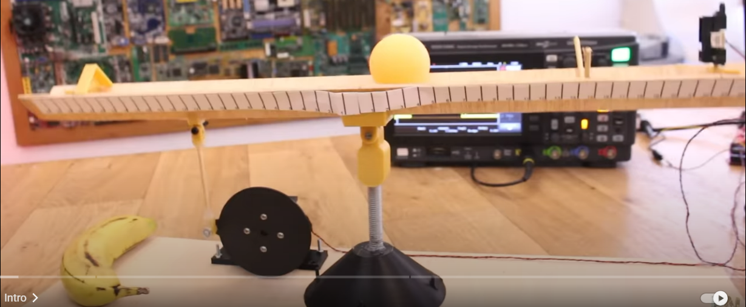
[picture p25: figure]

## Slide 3

Estrutura Física

Plataforma em contraplacado pintado de preto
Cruz branca no centro + borda de madeira visível
Dois braços 3D com suporte para servos
Pivô central com base côncava
Webcam fixa numa estrutura superior

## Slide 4

Estrutura Física

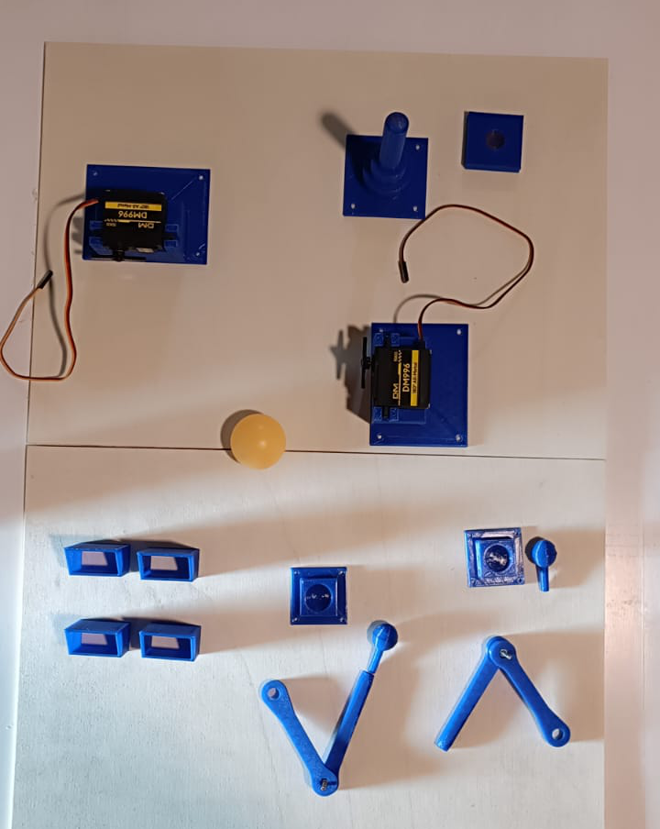
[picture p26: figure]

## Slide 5

Estrutura Física


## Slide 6

Eletrónica

Arduino UNO para controlo central
PCA9685 para controlar servos com precisão
2 servos DM996 (15 kg·cm)
Fonte de alimentação 6V / 72W
Webcam USB ligada ao PC

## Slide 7

Eletrónica


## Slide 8

Programação

Python (no PC):
OpenCV para visão
PID para controlo
Interface gráfica com sliders (CustomTkinter)
Envio de comandos para o Arduino

Arduino:
Recebe comandos via serial
Controla servos com PCA9685
Aplica limites de segurança definidos na calibração

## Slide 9

Programação

Python (no PC):

Arduino:


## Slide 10

Calibração dos servomotores


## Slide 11

Calibração PID


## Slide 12

Calibração PID


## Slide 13

Calibração PID


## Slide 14

Calibração PID


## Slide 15

Calibração Ziegler-Nichols – calibração ZN


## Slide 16

E se o sistema aprendesse sozinho?

"Será possível substituir a afinação manual por aprendizagem automática em tempo real, com base no comportamento observado?"

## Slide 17

Integração futura de algoritmos inteligentes

Aplicação direta em ambiente físico (sem simulação)
Ajuste automático de PID ou aprendizagem de estratégias com RL
Processo baseado em episódios, métricas reais e validação iterativa


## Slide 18

Comparação: Gymnasium vs OpenBalance


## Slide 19

Etapas para otimização/aprendizagem

Definir parâmetros a otimizar (ex: Kp, Ki, Kd)
Preparar sistema e segurança
Executar episódios com métricas
→ erro médio, tempo até falha, nº de colisões
Aplicar algoritmo de otimização
Hill Climbing, Q-Learning, etc
Avaliar e validar robustez final

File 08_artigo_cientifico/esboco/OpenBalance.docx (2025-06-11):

Universidade dos Açores

Pós-Graduação em Programação, Robótica e Inteligência Artificial (PRIA)

Relatório de Projeto Experimental

OpenBalance – Plataforma de Equilíbrio com Visão Computacional e Controlo PID

Autor: João Pavão

Docente: Prof. José Cascalho

Ponta Delgada, 14 de junho de 2025

# Resumo

Este relatório apresenta o desenvolvimento do projeto OpenBalance, uma plataforma robótica capaz de equilibrar uma bola através do controlo da inclinação da sua superfície. O sistema recorre a visão computacional para localizar a bola em tempo real e aplica algoritmos de controlo PID para manter a sua posição centrada. Desenvolvido no contexto da unidade curricular de Laboratório de Aplicações em Robótica e Aprendizagem (PRIA), este projeto combina conceitos de automação, controlo e inteligência artificial aplicada, com uma forte vertente pedagógica e open-source. Utiliza componentes como Arduino, servomotores, driver PCA9685 e uma webcam USB, integrados por uma interface gráfica construída em Python com CustomTkinter.

Palavras-chave: Visão Computacional, Controlo PID, Arduino, Robótica Educacional, OpenCV, CustomTkinter

# Índice

## 1. Introdução

O presente relatório documenta o desenvolvimento do projeto OpenBalance, uma plataforma robótica experimental concebida no âmbito da unidade curricular de Laboratório de Aplicações em Robótica e Aprendizagem (PRIA) da Universidade dos Açores. O sistema tem como principal objetivo demonstrar, de forma visual e interativa, os fundamentos do controlo automático aplicados a um problema clássico: o equilíbrio dinâmico de uma bola sobre uma superfície inclinável.

A ideia central consiste em permitir que uma bola se mantenha centrada numa plataforma bidimensional, cuja inclinação é controlada por dois servomotores, um em cada eixo (X e Y). A posição da bola é monitorizada em tempo real através de uma webcam USB, com processamento de imagem realizado em Python utilizando a biblioteca OpenCV. A decisão sobre os ângulos de inclinação é determinada por algoritmos de controlo PID (Proporcional–Integral–Derivativo), ajustáveis através de uma interface gráfica interativa desenvolvida com CustomTkinter.

O OpenBalance não é apenas uma implementação técnica; constitui também uma ferramenta pedagógica e de código aberto, pensada para facilitar o ensino e a aprendizagem de conceitos fundamentais de automação, controlo, robótica e visão computacional. A modularidade do sistema permite que seja facilmente replicado, adaptado e expandido, por exemplo para sistemas de maior complexidade como plataformas de Stewart (6 graus de liberdade).

Ao longo deste relatório serão apresentados os objetivos do projeto, os componentes utilizados, a estrutura de hardware e software desenvolvida, bem como as estratégias de calibração e os resultados obtidos. Será ainda feita uma reflexão sobre as potencialidades educativas do projeto e as perspetivas futuras para a sua evolução.

## 2. Objetivos

O projeto OpenBalance tem como objetivo principal o desenvolvimento de uma plataforma robótica educativa capaz de demonstrar o funcionamento de sistemas de controlo em tempo real, com particular enfoque no controlo PID e na visão computacional. Esta plataforma serve como um modelo físico interativo para o estudo de sistemas dinâmicos, permitindo a aplicação prática de conceitos abordados na unidade curricular de Laboratório de Aplicações em Robótica e Aprendizagem.

Objetivos específicos:

- Construir uma plataforma mecânica funcional que permita a inclinação controlada de uma superfície em dois eixos (X e Y), com servomotores de precisão;
- Integrar um sistema de aquisição de imagem em tempo real, utilizando uma webcam USB e a biblioteca OpenCV para deteção da posição de uma bola sobre a plataforma;
- Implementar algoritmos de controlo PID para estabilizar a posição da bola no centro da superfície, ajustando dinamicamente os ângulos dos servos;
- Desenvolver uma interface gráfica interativa (Dashboard) em Python com CustomTkinter, permitindo ao utilizador ajustar os parâmetros do controlo PID e da deteção de cor (HSV), bem como visualizar o vídeo e interagir com o sistema;
- Testar e calibrar o sistema físico e os algoritmos de controlo, otimizando o desempenho para diferentes condições;
- Documentar o processo de desenvolvimento, desde a conceção mecânica até à implementação do software, promovendo uma abordagem pedagógica, acessível e reprodutível;
- Explorar possibilidades de expansão futura, com destaque para:
  - A evolução da plataforma para sistemas com três ou mais braços de controlo, permitindo não só o equilíbrio passivo da bola mas também ações proativas e direcionadas sobre o movimento da mesma;
  - A conceção de um sistema tipo Stewart com seis graus de liberdade, oferecendo um campo de controlo tridimensional e potencial para simulações avançadas;
  - A incorporação de comportamentos mais interativos, como a capacidade de “bater” ou impulsionar a bola intencionalmente para zonas-alvo, baseando-se em inputs visuais e algoritmos de decisão;
  - A integração com algoritmos de inteligência artificial, nomeadamente aprendizagem por reforço, para que o sistema aprenda estratégias ótimas de controlo ou interação a partir da experiência acumulada.

Estas perspetivas futuras posicionam o OpenBalance como uma plataforma aberta, escalável e reprodutível, com potencial para projetos de investigação, ensino avançado e demonstrações interativas em contextos científicos ou educativos. Todo o código-fonte, esquemas eletrónicos, ficheiros de impressão 3D e documentação estão a ser organizados e publicados num repositório público no GitHub, promovendo a colaboração, a partilha de boas práticas em robótica educativa e a reutilização do projeto em contextos escolares, académicos ou pessoais. O projeto será disponibilizado sob licença open source, incentivando a sua adaptação, evolução e integração em futuras iniciativas.

## 3. Materiais e Montagem Física

### 3.1 Materiais Gerais

Bola leve (ex: esférica de pingue-pongue ou borracha macia)

Contraplacado fino (base da plataforma móvel)

Parafusos, porcas e anilhas M3 e M4

Cabos Dupont, terminais e fita dupla face

Tinta preta fosca (para contraste visual da plataforma)

Calha técnica em PVC (para suporte da webcam)

### 3.2 Eletrónica

Microcontrolador: Arduino UNO (ou compatível)

Módulo controlador de servos: PCA9685 (16 canais, I²C)

Servomotores: 2x DM996 (15 kg·cm, compatíveis com 6 V)

Fonte de alimentação: Fonte regulável 6 V / 72 W (com bornes)

Webcam USB: Câmera genérica HD (fixada em estrutura superior)

Cablagem adicional: fios, conectores macho-fêmea, ficha de alimentação

### 3.3 Estrutura Física e Impressão 3D

Braços articulados (x2): Impressos em PLA, com suporte para servos e encaixes de fixação à base

Suportes laterais: Estrutura rígida para montagem vertical dos servos

Pivô central: Elemento circular ou cónico, também em PLA, que permite rotação e estabilidade da plataforma

Encaixes tipo cavilha: Integrados nos braços para evitar deslizamento lateral

Plataforma móvel: Contraplacado pintado de preto com cruz central branca e borda natural visível (~4 mm) para facilitar a deteção por visão computacional

### 3.4 Montagem e Infraestrutura

Os braços 3D foram aparafusados diretamente aos servos, que por sua vez foram fixados às paredes laterais da base.

A plataforma repousa livremente sobre os braços, encaixando nos pinos e no pivô central para estabilidade e liberdade de movimento.

A webcam foi montada sobre uma calha técnica superior, garantindo uma visão perpendicular e estável de toda a área da plataforma.

O circuito foi montado numa breadboard lateral com ligações ao Arduino e à alimentação externa.

A fonte de alimentação foi cuidadosamente ajustada para fornecer 6 V estáveis e proteger os servos de sobrecargas.

## 4. Arquitetura do Sistema

O funcionamento do projeto OpenBalance assenta na integração de diversos subsistemas — deteção visual, controlo PID e interface gráfica — que comunicam entre si de forma coordenada. A arquitetura do sistema foi concebida para funcionar em tempo real, garantindo a resposta rápida necessária à estabilização da bola na plataforma.

### 4.1 Deteção Visual com OpenCV

A deteção da posição da bola é feita com recurso a uma webcam USB fixada verticalmente sobre a plataforma. A imagem captada é processada em Python, usando a biblioteca OpenCV, com o objetivo de localizar a bola em cada frame.

O processo é realizado da seguinte forma:

- Captura de imagem: Utiliza-se o cv2.VideoCapture() para capturar imagens da webcam em tempo real.
- Conversão de cores: A imagem é convertida do espaço BGR para HSV (cv2.cvtColor) para permitir uma segmentação mais robusta da cor da bola, mesmo com variações de luz.
- Filtragem por intervalo HSV: Aplicam-se máscaras (cv2.inRange) com base em valores ajustáveis via interface, permitindo identificar apenas a cor da bola.
- Tratamento morfológico: Usa-se erosão e dilatação para remover ruído e obter uma forma limpa.
- Localização do centroide: Com cv2.findContours e cv2.moments, calcula-se o centro (x, y) da bola, que representa a sua posição relativa na imagem.
- Escalonamento para coordenadas da plataforma: A posição em píxeis é convertida para uma escala proporcional à plataforma, usada no controlo PID.

A plataforma é pintada de preto com uma cruz branca no centro e uma borda natural de madeira visível (~4 mm), o que favorece o contraste visual e melhora a fiabilidade da deteção. Este sistema oferece uma taxa de atualização suficiente para aplicações de controlo em tempo real (≥ 20 FPS em máquinas comuns).

### 4.2 Controlo PID e Comando da Plataforma

A posição da bola em relação ao centro da plataforma é usada como erro de entrada para dois controladores PID, um para cada eixo (X e Y).

O algoritmo calcula a correção necessária para devolver a bola ao centro, ajustando os ângulos dos servos.

- PID em Python: O cálculo do PID é realizado diretamente em Python, com fórmulas discretas para as componentes proporcional, integral e derivativa:

onde e(t) é a distância da bola ao centro nos eixos X ou Y.

- Conversão para ângulo de servo: O sinal de controlo resultante do PID é mapeado para um intervalo de ângulos seguros (por exemplo, 80º a 120º para X e 70º a 110º para Y).
- Envio de comandos ao Arduino: Os valores de ângulo são enviados via comunicação serial para o Arduino, que aciona os servos através do driver PCA9685.
- Arduino como interface de controlo:
  - Recebe comandos via porta serial (ex: "X105Y95").
  - Usa a biblioteca Adafruit PWM Servo Driver para controlar os servos em PWM de 16 canais.
  - Aplica os ângulos com limites de segurança definidos durante a fase de calibração.

Esta separação de responsabilidades permite que o controlo lógico e visual seja feito no PC, enquanto o controlo físico é delegado ao microcontrolador, aumentando a robustez e modularidade do sistema.

### 4.3 Interface Gráfica em Python

A interface gráfica foi desenvolvida com a biblioteca CustomTkinter, que permite criar GUIs modernas com tema escuro, sliders estilizados e separação por painéis.

A interface está dividida em três áreas principais:

- Painel HSV (deteção da bola):
  - Sliders para ajuste em tempo real dos limites de Hue, Saturation e Value;
  - Vista prévia da máscara HSV gerada, permitindo afinar a segmentação;
  - Botão para guardar os valores de HSV em ficheiro CSV.
- Painel PID (controlo da plataforma):
  - Sliders para ajuste dos parâmetros Kp, Ki e Kd para cada eixo;
  - Visualização numérica dos valores;
  - Possibilidade de reiniciar os acumuladores do PID;
  - Gravação de presets em CSV para teste posterior.
- Painel de vídeo e controlo:
  - Visualização em tempo real do vídeo processado com sobreposição da posição da bola;
  - Botões para iniciar/pausar seguimento, ligar motores e selecionar a porta serial do Arduino;
  - Deteção automática das portas COM disponíveis.

Toda a lógica de controlo, comunicação e processamento está integrada na interface, o que facilita a interação com o sistema e a experimentação com diferentes configurações. A interface foi projetada para ser pedagógica, intuitiva e extensível.

## 5. Calibração dos Serrvomotores

A calibração dos servomotores é um passo crítico para garantir o bom funcionamento da plataforma móvel do OpenBalance, pois define os limites físicos de inclinação e assegura que os movimentos da plataforma correspondem corretamente aos comandos enviados pelo sistema de controlo PID.

Procedimento Inicial de Calibração

Antes de iniciar o controlo automático, foi necessário determinar os ângulos mínimos e máximos seguros para cada servo (eixo X e Y), de modo a evitar esforços excessivos, vibrações ou colisões com a estrutura.

1. Posição neutra (90°):
  - Cada servo foi inicialmente posicionado a 90°, correspondente à posição horizontal da plataforma.
  - A montagem dos braços 3D foi feita com a plataforma nivelada nesta posição, garantindo simetria.
2. Limites físicos:
  - Através de testes manuais e observação, foram definidos intervalos seguros para cada servo:
    - Eixo X: aproximadamente 80° a 120°
    - Eixo Y: aproximadamente 70° a 110°
  - Estes valores dependem da montagem física, da folga mecânica e da rigidez dos materiais.
3. Estabilização da estrutura:
  - Para garantir precisão, foram adicionados encaixes tipo cavilha nos braços 3D e uma base côncava no pivô central, evitando folgas laterais.
  - A plataforma foi construída de modo a não ser muito lisa, aumentando a aderência sem prejudicar o deslizamento suave da bola.

Implementação da Calibração no Código

A calibração foi incorporada diretamente no código Arduino, responsável por acionar os servos via o módulo PCA9685:

- Foram definidos limites máximos e mínimos para cada servo, de modo que os valores recebidos do computador fossem automaticamente restringidos dentro da faixa segura;
- Foi criado um modo de teste manual na dashboard, permitindo enviar ângulos específicos e observar o movimento da plataforma em tempo real;
- A lógica de controlo no Arduino converte os ângulos em pulsos PWM compatíveis com os servos DM996, respeitando o mapeamento definido na calibração.

Exemplo de pseudocódigo para mapeamento:

if (anguloX > 120) anguloX = 120;

if (anguloX < 80) anguloX = 80;

Validação com Feedback Visual

Durante a calibração, a posição da plataforma foi monitorizada com a webcam instalada na parte superior. Esta abordagem permitiu:

- Ajustar a inclinação máxima sem sair do campo de visão da câmara;
- Garantir que a plataforma se mantinha estável em repouso (90°);
- Verificar que os movimentos em X e Y não causavam oscilações indesejadas ou contacto com os limites físicos.

A calibração adequada dos servos garante não só a segurança mecânica do sistema, mas também o bom desempenho do controlo PID, pois permite respostas consistentes e previsíveis aos comandos de correção enviados pelo algoritmo.

## 6. Testes e Resultados Preliminares

Após a montagem física e implementação do software, foi realizada uma bateria completa de testes para validar o comportamento do sistema OpenBalance em condições reais de operação. Os testes envolveram a deteção visual da bola, o controlo PID em tempo real e a resposta física da plataforma acionada por servomotores, com resultados globalmente positivos.

Deteção Visual com OpenCV

A deteção da bola revelou-se estável e precisa após o ajuste adequado dos parâmetros HSV na interface gráfica:

- Foram testadas bolas de várias cores e materiais, sendo as de cor laranja mate e amarela as que ofereceram melhor contraste sobre a plataforma preta;
- A máscara HSV gerada por OpenCV foi eficaz na maioria das condições de iluminação, especialmente sob luz difusa e estável;
- A presença de uma cruz branca central e uma borda natural visível (~4 mm) permitiu localizar claramente o centro e os limites da plataforma, melhorando a calibração espacial;
- A taxa de atualização de vídeo situou-se entre 20 e 25 FPS, suficiente para aplicações em controlo dinâmico.

Desempenho do Controlo PID

Com os valores de PID ajustados via sliders, o sistema demonstrou boa capacidade de manter a bola próxima do centro da plataforma:

- A componente proporcional K_p teve maior influência no retorno rápido da bola ao centro;
- O termo derivativo K_d suavizou significativamente os movimentos, reduzindo oscilações;
- O uso controlado da componente integral K_i ajudou a corrigir desvios persistentes sem causar instabilidade;
- A bola foi capaz de recuperar de pequenas perturbações e manteve-se estável em repouso, validando a eficácia do controlo PID implementado.

Comportamento Físico da Plataforma

A estrutura da plataforma e os servomotores apresentaram desempenho satisfatório:

- Os limites de inclinação previamente definidos (X: 80°–120°, Y: 70°–110°) mostraram-se adequados, evitando impactos ou movimentos bruscos;
- Os servos DM996 responderam de forma consistente, com precisão e força suficiente para inclinar suavemente a superfície;
- A plataforma foi nivelada com sucesso, e a bola manteve-se centrada durante longos períodos de teste;
- A webcam montada na calha superior permitiu uma visão clara e estável de toda a superfície da plataforma.

Registo e Otimização

Todos os testes foram devidamente registados:

- Foram guardados presets de valores PID e HSV em ficheiros CSV para reutilização;
- A interface gráfica demonstrou ser um apoio essencial para afinação em tempo real;
- O código e dados obtidos foram integrados no repositório GitHub, garantindo transparência e partilha do conhecimento;
- Vídeos e capturas de ecrã documentaram o desempenho do sistema e serão utilizados na apresentação final.

Com os testes realizados, conclui-se que o OpenBalance cumpre com sucesso os objetivos definidos: demonstrar o funcionamento de um sistema de controlo em tempo real com feedback visual, utilizando uma abordagem acessível, modular e educativa.

## 7. Conclusão e Perspetivas Futuras

O desenvolvimento do projeto OpenBalance permitiu integrar, de forma prática e aplicada, os conhecimentos adquiridos ao longo da unidade curricular de Laboratório de Aplicações em Robótica e Aprendizagem (PRIA). Através da construção de uma plataforma física capaz de equilibrar uma bola com base em visão computacional e controlo PID, foi possível explorar conceitos fundamentais de automação, eletrónica, programação e inteligência artificial aplicada.

A abordagem adotada foi orientada para a simplicidade, modularidade e reprodutibilidade, utilizando componentes acessíveis e software open-source. A integração de uma interface gráfica interativa permitiu não só afinar os parâmetros de controlo, mas também tornar o sistema mais pedagógico e visualmente compreensível. A utilização de Python com OpenCV e CustomTkinter, aliada à comunicação serial com o Arduino, mostrou ser uma solução eficaz e flexível para sistemas robóticos educativos.

Do ponto de vista pedagógico, o projeto destacou-se como uma ferramenta de elevada aplicabilidade no ensino de controlo automático, visão computacional e robótica, podendo ser facilmente replicado em contexto escolar ou universitário. A capacidade de visualizar em tempo real a resposta de um sistema PID perante estímulos externos reforça a ligação entre teoria e prática, promovendo a aprendizagem ativa.

Dito pelo ChatGPT:

Aqui está a Secção 7 — Conclusão e Perspetivas Futuras, com foco na reflexão crítica, contributos pedagógicos e caminhos de evolução do projeto OpenBalance. Está estruturada para fechar o relatório de forma forte e articulada com os objetivos da pós-graduação PRIA.

7. Conclusão e Perspetivas Futuras

O desenvolvimento do projeto OpenBalance permitiu integrar, de forma prática e aplicada, os conhecimentos adquiridos ao longo da unidade curricular de Laboratório de Aplicações em Robótica e Aprendizagem (PRIA). Através da construção de uma plataforma física capaz de equilibrar uma bola com base em visão computacional e controlo PID, foi possível explorar conceitos fundamentais de automação, eletrónica, programação e inteligência artificial aplicada.

A abordagem adotada foi orientada para a simplicidade, modularidade e reprodutibilidade, utilizando componentes acessíveis e software open-source. A integração de uma interface gráfica interativa permitiu não só afinar os parâmetros de controlo, mas também tornar o sistema mais pedagógico e visualmente compreensível. A utilização de Python com OpenCV e CustomTkinter, aliada à comunicação serial com o Arduino, mostrou ser uma solução eficaz e flexível para sistemas robóticos educativos.

Do ponto de vista pedagógico, o projeto destacou-se como uma ferramenta de elevada aplicabilidade no ensino de controlo automático, visão computacional e robótica, podendo ser facilmente replicado em contexto escolar ou universitário. A capacidade de visualizar em tempo real a resposta de um sistema PID perante estímulos externos reforça a ligação entre teoria e prática, promovendo a aprendizagem ativa.

Perspetivas Futuras

Tendo por base a experiência adquirida, identificam-se várias possibilidades de evolução do projeto:

- Expansão para uma plataforma com mais graus de liberdade, como uma estrutura tipo Stewart (6 DOF), permitindo simulações complexas em 3D;
- Adição de braços articulados com capacidade de interação ativa com a bola, incluindo movimentos como empurrar ou redirecionar a trajetória — abrindo portas a sistemas com objetivos dinâmicos, como "jogar" com a bola;
- Integração de algoritmos de inteligência artificial, como aprendizagem por reforço, permitindo que o sistema aprenda estratégias de controlo através de tentativa e erro, otimizando automaticamente os ganhos PID ou desenvolvendo comportamentos mais sofisticados;
- Uso de câmaras de maior resolução e computação embarcada com Raspberry Pi, permitindo processamento autónomo e maior portabilidade;
- Aplicação em contextos competitivos ou demonstrativos, como feiras de ciência ou o AzoresBot, onde o sistema pode ser apresentado de forma interativa ao público.

Em suma, o OpenBalance posiciona-se como um projeto com elevado valor educativo, passível de expansão em múltiplas direções — desde aplicações pedagógicas básicas até desafios de investigação avançada. O seu caráter open-source e a documentação completa disponibilizada no GitHub garantem a continuidade, partilha e evolução por parte de outros alunos, docentes ou entusiastas da robótica.

## 8. Bibliografia e Recursos

### 8.1 Bibliografia

Controlo e Automação

- Ogata, K. (2010). Modern Control Engineering (5th ed.). Prentice Hall.
- Dorf, R. C., & Bishop, R. H. (2017). Modern Control Systems (13th ed.). Pearson.
- Nise, N. S. (2020). Control Systems Engineering (8th ed.). Wiley.

Robótica Educacional e Arduino

- Blum, J. (2013). Exploring Arduino: Tools and Techniques for Engineering Wizardry. Wiley.
- Monk, S. (2016). Programming Arduino: Getting Started with Sketches (2nd ed.). McGraw-Hill Education.

Python, OpenCV e Interfaces Gráficas

- Beyeler, M. (2017). Machine Learning for OpenCV. Packt Publishing.
- Laganière, R. (2014). OpenCV 3 Computer Vision Application Programming Cookbook. Packt Publishing.
- Chen, J. (2023). Learn OpenCV with Python by Examples.
- Harrison, M. (2017). Tkinter GUI Programming by Example. Packt Publishing.

### 8.2 Webgrafia

GitHub — JohanLink:

https://github.com/JohanLink/Ball-Balancing-PID-System

GitHub — giusenso:

https://github.com/giusenso/Ball-Balancing-PID-System

Thingiverse – Ball Balancing PID Robot:

https://www.thingiverse.com/thing:4457405

Documentação OpenCV:

https://docs.opencv.org

Biblioteca Adafruit PWM Servo Driver (PCA9685):

https://learn.adafruit.com/16-channel-pwm-servo-driver

CustomTkinter – GUI Moderna para Python:

https://github.com/TomSchimansky/CustomTkinter

Introdução ao Controlo PID (PID Explained):

https://www.controleng.com/articles/pid-control-explained

Curso de Controlo PID com Arduino (Maker):

https://www.makerguides.com/arduino-pid-controller

### 8.3 Prompts utilizados (ChatGPT/OpenAI)

Durante o processo de desenvolvimento e documentação, foram utilizados vários prompts para obter apoio técnico, estrutural e criativo, incluindo:

- “Cria uma estrutura de relatório técnico para um projeto de controlo PID com visão computacional.”
- “Explica como calibrar servos com Arduino usando PCA9685.”
- “Como implementar controlo PID em Python com comunicação serial para Arduino?”
- “Sugere uma interface gráfica com CustomTkinter para controlo PID e HSV em tempo real.”
- “Descreve os passos de testes e validação de um sistema que equilibra uma bola com feedback visual.”
- “Adiciona perspetivas futuras para uma plataforma de controlo com múltiplos braços e IA.”
- “Faz uma reflexão final para relatório técnico com foco pedagógico e open-source.”

OpenBalance página 2 de 10

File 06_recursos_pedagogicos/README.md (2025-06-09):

# 📁 06_recursos_pedagogicos

Fichas práticas, planos de aula, guias para professores e sugestões de exploração interdisciplinar (robótica, física, IA, visão computacional).

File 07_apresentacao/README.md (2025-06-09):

# 📁 07_apresentacao

Slides, posters, vídeos e outros materiais para apresentação do projeto no PRIA, escolas, eventos ou feiras de ciência.

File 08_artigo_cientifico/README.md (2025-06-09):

# 📁 08_artigo_cientifico

Manuscrito científico e relatório técnico. Contém texto académico, bibliografia, figuras e dados experimentais para submissão PRIA.

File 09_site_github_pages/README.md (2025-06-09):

# 📁 09_site_github_pages

Estrutura para publicação do projeto como site no GitHub Pages. Inclui `index.md`, tutoriais, galeria de imagens e contactos.

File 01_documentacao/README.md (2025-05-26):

# 📁 01_documentacao

Esta pasta contém o planeamento do projeto, objetivos, cronogramas, e anotações pedagógicas relacionadas com a disciplina de Laboratório de Robótica.

Inclui também análise de projetos semelhantes e reflexões ligadas ao PRIA.

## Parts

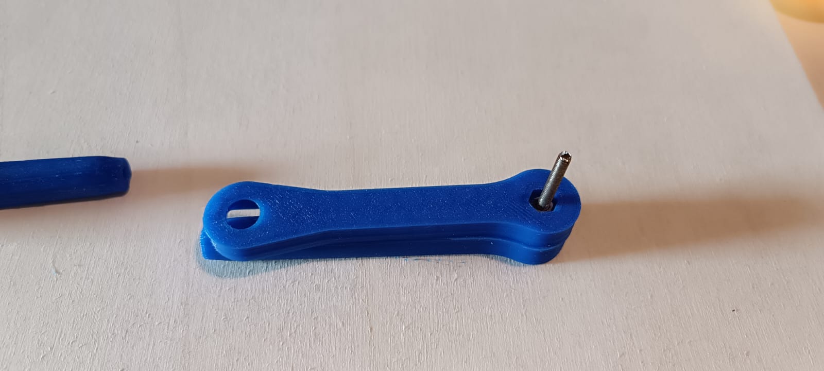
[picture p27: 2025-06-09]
02_estrutura_fisica/fotos_componentes/Mecanica_14.jpg

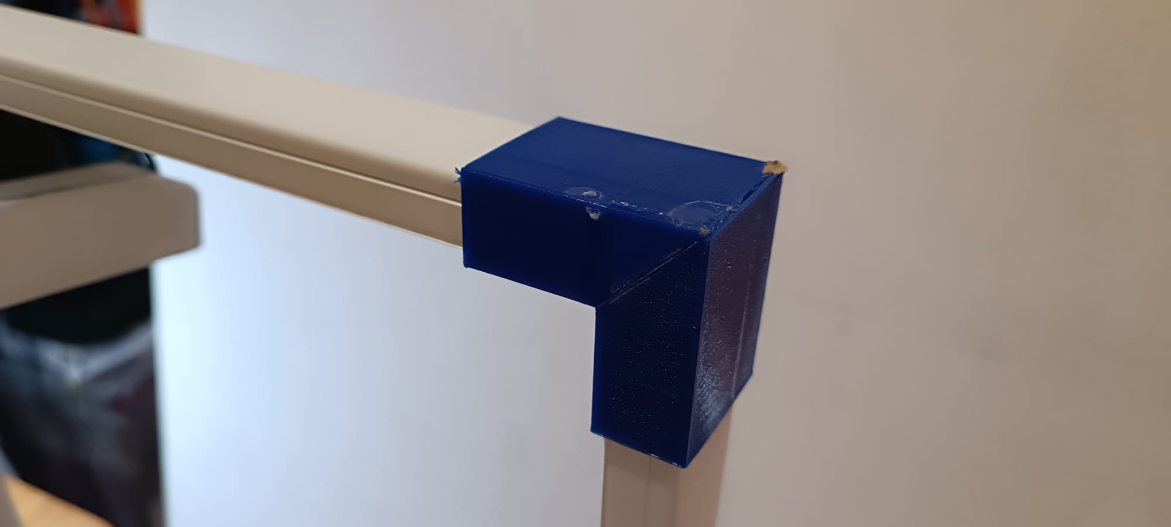
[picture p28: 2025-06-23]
02_estrutura_fisica/fotos_componentes/Estrutura_6.jpg

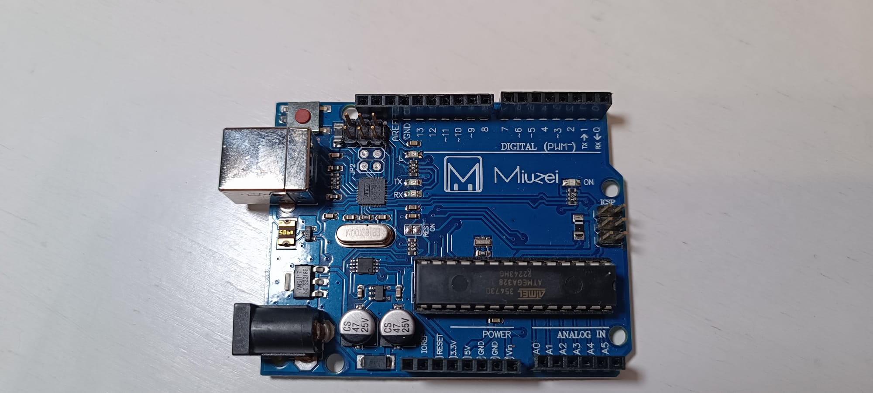
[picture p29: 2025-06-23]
02_estrutura_fisica/fotos_componentes/Eletronica_5.jpg

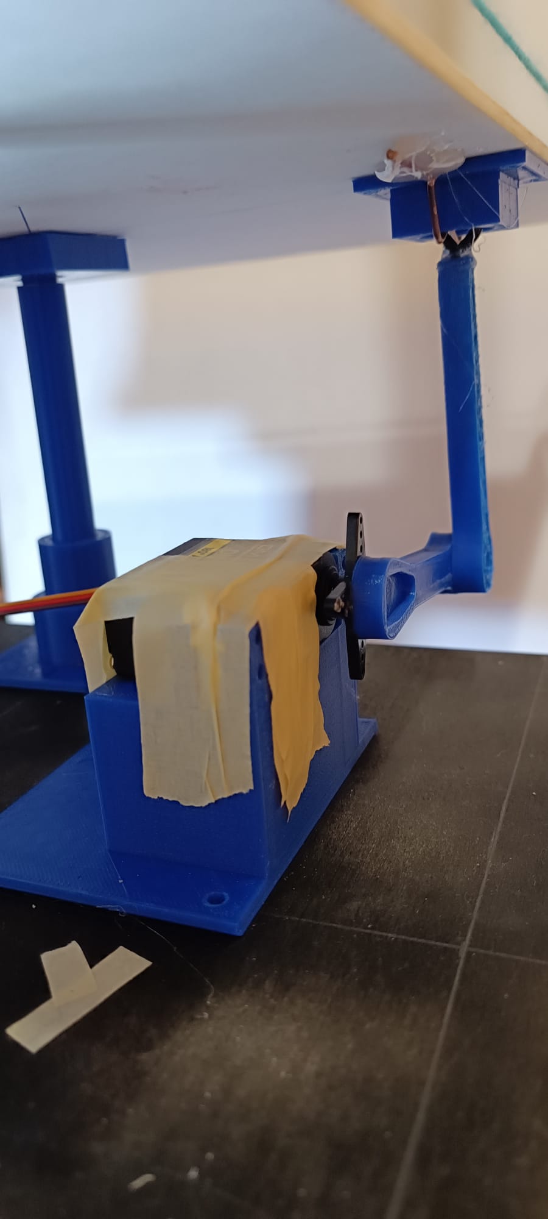
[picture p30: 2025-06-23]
02_estrutura_fisica/fotos_componentes/Mecanica_4.jpg

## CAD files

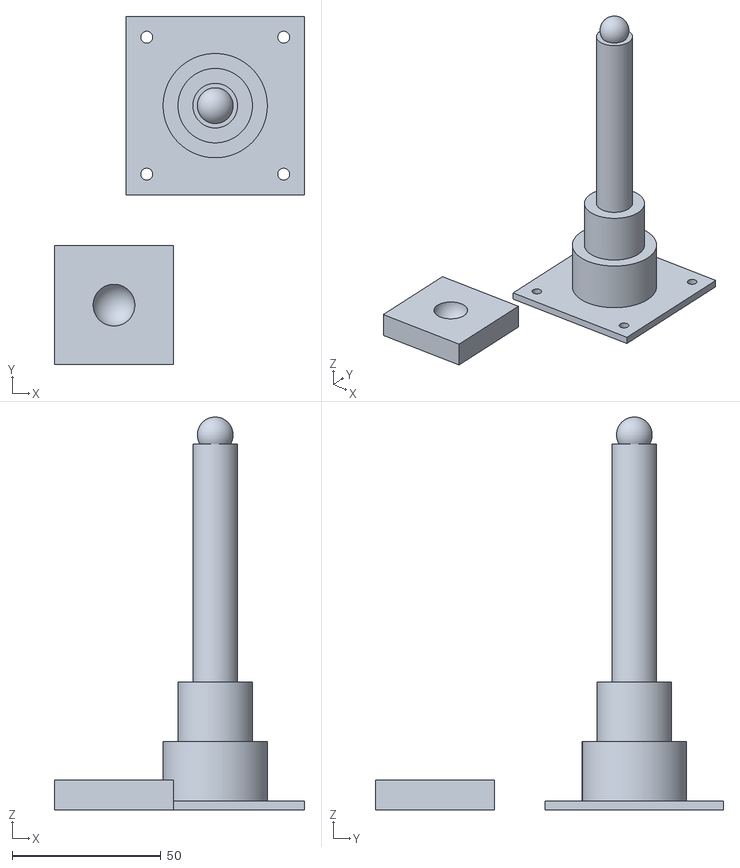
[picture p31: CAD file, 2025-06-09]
02_estrutura_fisica/STL/Eixo Central Ball Balancer.stl
84.0 x 117.0 x 132.0

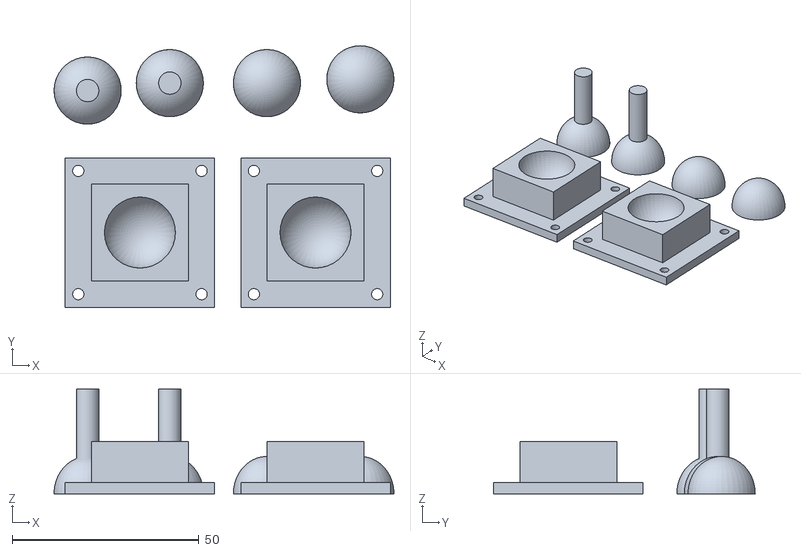
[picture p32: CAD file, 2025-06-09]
02_estrutura_fisica/STL/braco_v2.stl
91.0 x 70.0 x 28.0

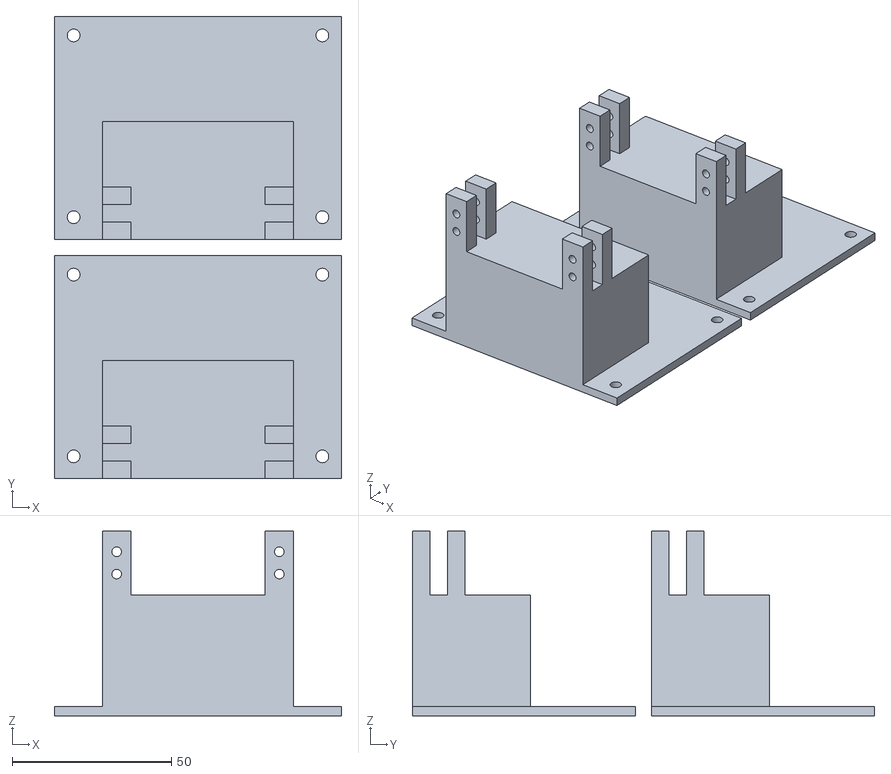
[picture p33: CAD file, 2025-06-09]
02_estrutura_fisica/STL/2 Eixos BALL suporte.stl
90.0 x 145.0 x 58.0

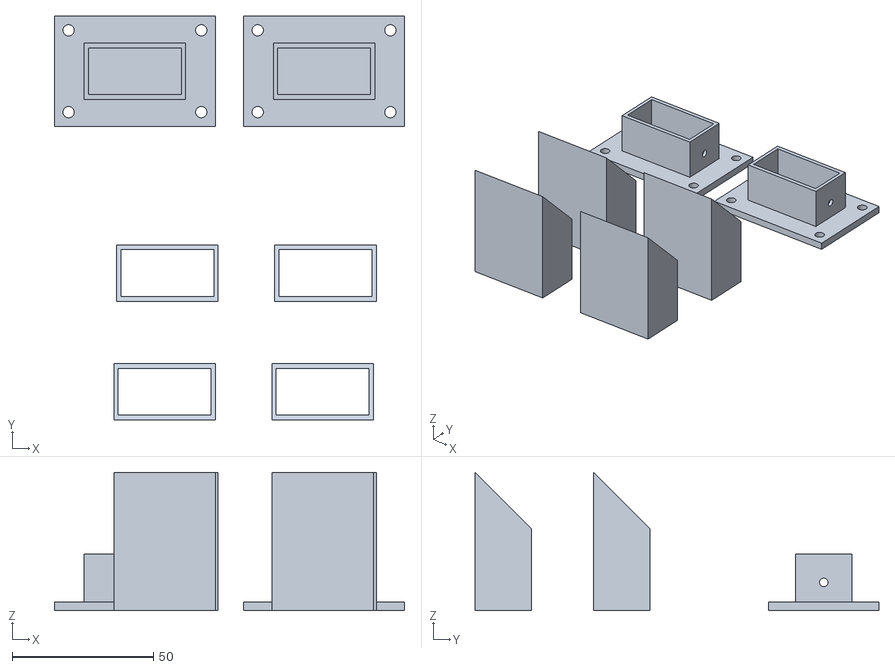
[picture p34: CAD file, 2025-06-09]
02_estrutura_fisica/STL/Suporte uniao camara OpenBalance.stl
124.0 x 143.0 x 49.0

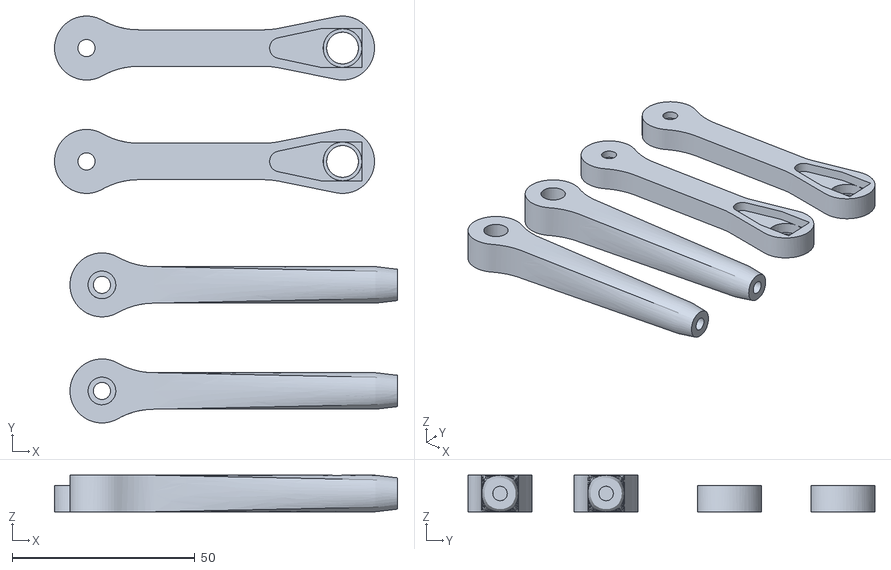
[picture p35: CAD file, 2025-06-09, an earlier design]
02_estrutura_fisica/STL/braco_v1.stl
93.8 x 111.2 x 10.0

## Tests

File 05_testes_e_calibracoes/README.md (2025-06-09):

# 📁 05_testes_e_calibracoes

Registo de testes e medições experimentais. Inclui logs de desempenho, gráficos, vídeos de funcionamento e valores de PID testados.

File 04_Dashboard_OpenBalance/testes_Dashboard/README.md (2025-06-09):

# OpenBalance Dashboard

Interface gráfica em Python para controle de uma plataforma de equilíbrio de bola, com visão computacional, PID em tempo real e ferramentas de calibração.

---

## 🖥️ Visão Computacional HSV
- Ajuste interativo de filtros HSV via **sliders** e **presets coloridos**  
- Preview em tempo real do feed de vídeo ou da máscara segmentada  
- Cruz de referência central e definição de ponto-alvo por **clique** na imagem  

## ⚙️ Controle PID
- Sliders de **Kp**, **Ki**, **Kd** com leitura imediata  
- Botão **“Aplicar Ganhos”** para atualizar o controlador sem reiniciar  
- Envio serial das coordenadas de erro (-X,-Y) ao Arduino/PCA9685  

## 🔧 Calibração de Servos
- Suporte ao **PCA9685 16-ch PWM** + servos MG996/DM996  
- Aba **“Calibração”** com:
  - **Offset central** (µs) para nivelamento fino  
  - **Limites de pulso** (mín./máx.) e botões de teste dedicados  
- Constrain automático dos ângulos aos limites mecânicos seguros  

## 🗄️ Configuração & Persistência
- **Salvar/Carregar** ajustes HSV, PID e calibração em arquivos **JSON** ou **CSV**  
- **Status bar** para feedback de sucesso/erro  
- Layout responsivo em **modo escuro** (dark-blue) com menus nativos  

---

## 🚀 Como usar

1. **Ajuste o filtro HSV** até isolar apenas a bola no feed.  
2. **Conecte** ao Arduino/PCA9685 e **teste** posições mín./máx. na aba Calibração.  
3. **Clique** no vídeo para definir um novo ponto-alvo ou use o centro padrão.  
4. **Aplique os ganhos PID** e habilite o “Seguimento” para manter a bola estável.  
5. **Salve** sua configuração para reutilização futura.

---

## 📄 Licença

Distribuído sob a licença **MIT**. Veja [LICENSE](LICENSE) para detalhes.

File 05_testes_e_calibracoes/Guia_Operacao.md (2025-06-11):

# 📋 Guia de Operação e Checklist do OpenBalance

✨ Parabéns por chegar à fase final do projeto OpenBalance! ✨

Este guia é a sua checklist definitiva para arrancar, calibrar e operar a sua plataforma de equilíbrio de forma segura e eficiente. Siga cada passo na ordem correta para garantir um arranque perfeito.

---

## Fase 1: Preparação e Verificação do Hardware 🛠️🔌

A segurança em primeiro lugar! Antes de ligar qualquer fonte de alimentação, vamos garantir que todas as ligações estão corretas.

*   [ ] **1. Desligue Tudo:** Certifique-se de que a fonte de alimentação externa de 6V e o cabo USB do Arduino estão completamente desligados.

*   [ ] **2. Verifique as Ligações Físicas:** Dê uma última olhada em todas as ligações.
    *   [   ] **🔌 USB:** O Arduino está ligado ao seu computador via cabo USB.
    *   [ ] **🔗 I²C:** Os pinos `SDA` e `SCL` do Arduino estão ligados aos pinos `SDA` e `SCL` do módulo PCA9685.
    *   [ ] **🤖 Servos:** O servo do eixo **X** está ligado ao **canal 0** do PCA9685. O servo do eixo **Y** está ligado ao **canal 1**.
    *   [ ] **⚡ Alimentação Externa:** A sua fonte de 6V está ligada aos bornes `V+` (positivo) e `GND` (negativo) do PCA9685.
    *   [ ] **🌍 Terra Comum (CRÍTICO!):** Existe um fio a ligar um pino `GND` do PCA9685 a um pino `GND` do seu Arduino. Sem isto, a comunicação I²C não funcionará corretamente.

---

## Fase 2: Calibração Física e Recolha de Dados 📝📐

Nesta fase, usamos uma ferramenta de diagnóstico (o seu script de calibração manual) para descobrir os limites físicos da sua plataforma.

*   [ ] **1. Carregar o Script de Calibração Manual:**
    *   Ligue **apenas** o cabo USB do Arduino ao computador.
    *   Abra o Arduino IDE e carregue o seu **script de calibração** (o que responde a comandos como `X90`, `Y80`, etc.).

*   [ ] **2. Abrir o Serial Monitor:**
    *   No Arduino IDE, abra o **Serial Monitor** (`Ctrl+Shift+M`).
    *   Verifique se a velocidade (baudrate) está definida para **9600**.

*   [ ] **3. Descobrir e Anotar os Ângulos ✍️:**
    *   Agora, ligue a sua fonte de alimentação externa de 6V.
    *   Envie comandos pelo Serial Monitor para encontrar os ângulos exatos. Seja paciente e encontre o valor perfeito para cada um. Anote-os aqui:

    ```
    -------------------------------------------
    VALORES DE CALIBRAÇÃO FÍSICA
    -------------------------------------------
    Preencher de cada vez que fizer a montagem	

    Ângulo de Equilíbrio X (e.g., 90): 100
    Ângulo Mínimo X        (e.g., 60): ______
    Ângulo Máximo X       (e.g., 120): ______

    Ângulo de Equilíbrio Y (e.g., 80): 80
    Ângulo Mínimo Y        (e.g., 50): 55
    Ângulo Máximo Y       (e.g., 110): ______
    -------------------------------------------
    ```
    *   Quando terminar, **desligue a fonte de alimentação externa**.

---

## Fase 3: Configuração do Sistema Final ⚙️🚀

Com os dados recolhidos, vamos carregar o software final e configurar a dashboard.

*   [ ] **1. Carregar o Firmware Final:**
    *   **Feche o Serial Monitor** no Arduino IDE (um passo crucial!).
    *   Abra o **firmware final e completo** que preparámos (para o PCA9685, com `SERVO_FREQ = 250`).
    *   Carregue este firmware para o seu Arduino.

*   [ ] **2. Executar a Dashboard Python:**
    *   No seu computador, execute a aplicação `OpenBalance Dashboard v5.0`.

*   [ ] **3. Ligar e Configurar na Dashboard:**
    *   No separador **"Operação"**, clique em **"Ligar"** para estabelecer a comunicação com o Arduino.
    *   Vá para o separador **"Assistente de Calibração (º)"**.
    *   Introduza os 6 ângulos que anotou na fase anterior nos campos correspondentes.
    *   Clique no botão **"Calcular e Aplicar para o separador Calibração (μs)"**. A magia aconteceu! ✨

*   [ ] **4. Verificar a Configuração:**
    *   Vá ao separador **"Calibração (μs)"**. Verifique se os campos foram preenchidos com valores numéricos (microssegundos).
    *   Ligue novamente a fonte de alimentação externa de 6V.
    *   Use os botões **"T"** para testar cada limite e o botão **"Testar Posição Central"** para confirmar que a plataforma se move como esperado.

---

## Fase 4: Operação e Sintonização Fina 🧠🟢

Tudo pronto para o "Go Live"!

*   [ ] **1. Preparar para o Controlo:**
    *   Vá para o separador **"Operação"**.
    *   Clique em **"Ligar Motores"**.
    *   No painel de vídeo, certifique-se de que a checkbox **"Filtro de Kalman"** está marcada (recomendado).
    *   No painel esquerdo, configure o **filtro HSV** para detetar a sua bola de forma fiável (um círculo verde deve aparecer à volta dela).

*   [ ] **2. Iniciar o Controlo Ativo:**
    *   Coloque a bola gentilmente no centro da plataforma.
    *   Clique em **"Ligar Seguimento"**. O sistema está agora a tentar ativamente equilibrar a bola.

*   [ ] **3. Sintonizar o PID:**
    *   Agora é a sua vez! Ajuste os 6 ganhos do PID (Kp, Ki, Kd para X e Y) até que a bola fique estável e o sistema responda de forma suave e precisa. Comece com valores pequenos e aumente gradualmente.

---

## Fase 5: Desligar de Forma Segura 🛑😴

Siga sempre esta ordem para desligar o sistema.

*   [ ] **1. Pare o Controlo no Software:**
    *   Na dashboard, clique em **"Parar Seguimento"**.
    *   Clique em **"Desligar Motores"**.
*   [ ] **2. Feche a Aplicação:**
    *   Feche a janela da aplicação Python. A sua última configuração será guardada automaticamente no `config.json`.
*   [ ] **3. Desligue o Hardware:**
    *   Desligue a fonte de alimentação externa de 6V.
    *   Desligue o cabo USB do Arduino.

---

## 🤔 Dicas Rápidas e Troubleshooting

*   **Servos não se movem?** Verifique a alimentação externa de 6V, a ligação de terra comum e as ligações I²C.
*   **Dashboard não liga ao Arduino?** Verifique se selecionou a porta COM correta e se o Serial Monitor do Arduino IDE está fechado.
*   **Movimento muito "nervoso" ou com "zumbido"?** Certifique-se de que o Filtro de Kalman está ativo. Se ainda assim acontecer, diminua os seus ganhos `Kd` e `Kp`.
*   **A bola "foge" sempre para um lado?** Verifique a sua calibração de equilíbrio no Assistente, ou pode ser que o seu ganho `Kp` esteja com o sinal invertido (raro, mas possível dependendo da montagem).

## 🎉 Parabéns!

Você construiu, configurou e operou com sucesso uma plataforma de equilíbrio avançada. Este é um feito de engenharia que combina mecânica, eletrónica e software. Bom trabalho! 🏆

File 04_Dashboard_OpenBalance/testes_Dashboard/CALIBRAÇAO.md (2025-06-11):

CALIBRAÇAO dos Motores Servo da plataforma OpenBalance

MOTOR X (eixo x da plataforma)

posição de equilíbrio - 90º

LIMITES de SAIDA
Mínimo - 60º (angulo de 10º inclinação)
Máximo - 120º (angulo de 10º de inclinação)
Intervalos de segurança para o servo motor x:
de 60º (mínimo) a 120º (máximo) onde 90º é a posição de equilíbrio.
Corresponde a inclinações de 10 graus (quando se encontra no mínimo) para um lado e de 10 graus (quando se encontra no máximo ) para o outro lado.

MOTOR Y (eixo y da plataforma)
posição de equilíbrio - 80º

LIMITES de SAIDA
Mínimo - 50º (angulo de 12º inclinação)
Máximo - 110º (angulo de 15º de inclinação)

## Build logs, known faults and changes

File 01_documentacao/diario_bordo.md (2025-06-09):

# 📘 Diário de Bordo – Projeto Sistema de Equilíbrio com PID

**Autor:** João Pavão  
**Projeto:** Ball Balancing PID System  
**Período:** Maio – Julho 2025  
**Instituição:** PRIA – Universidade dos Açores

---

## 📅 Semana 1 – [27 Maio a 2 Junho]

**Objetivos da semana:**
- Definir o modelo final a usar (3 servos com braço articulado)
- Iniciar a impressão 3D dos primeiros braços
- Rever documentação técnica de Johan Link

**Tarefas realizadas:**
- Análise técnica das versões com 2 braços (motores servo)
- Estudo dos desenhos técnicos e medidas dos braços
- Impressão de protótipo de um braço inferior e superior
- Criação de pasta estruturada do projeto

**Dificuldades encontradas:**
- Determinação do encaixe ideal para esferas (R5)
- Definição dos limites de movimento mecânico
- Tolerâncias nos furos para parafusos

**Notas e reflexões:**
- A versão com estrutura simples em madeira parece ideal para testes rápidos
- O projeto é viável até julho com entregas modulares
- Estrutura de pastas no PC organizada para acompanhar todas as fases do projeto

---

## 📅 Semana 2 – [3 a 9 Junho]

**Objetivos:**
- Imprimir todos os braços e montar estrutura completa
- Fixar servos na base e testar movimento com Arduino
- Criar código básico de movimentação

**Tarefas realizadas:**
_(a preencher ao longo da semana)_

**Dificuldades encontradas:**
_(a preencher)_

**Notas:**
_(a preencher)_

---

## 📅 Semana 3 – [10 a 16 Junho]

**Objetivos:**
- Iniciar testes com controlo PID
- Testar movimento X e Y em tempo real
- Calibrar valores Kp, Ki, Kd com sliders

...

---

## ✅ Observações gerais

- Este diário será atualizado semanalmente até à entrega do projeto em julho.
- Serve como registo técnico e reflexivo das decisões tomadas.
- Todos os ficheiros, STL e código estarão disponíveis no repositório OpenBalance

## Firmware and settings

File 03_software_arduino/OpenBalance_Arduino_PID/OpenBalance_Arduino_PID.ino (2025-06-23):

/*
===============================================================================
Projeto: OpenBalance - Sistema de Equilíbrio de Bola com Controlo PID
Ficheiro: OpenBalance_Arduino_PID.ino
Descrição: Código para Arduino que controla dois servomotores via PCA9685.
           Implementa controlo PID por eixo com receção de erro via serial.
Autor: João Pavão
Data: 22/06/2025
Disciplina: Laboratório de Aplicações em Robótica e Aprendizagem (PRIA)
Instituição: Universidade dos Açores
Versão: v1.0
Licença: MIT License
===============================================================================
Notas:
- Este ficheiro integra o sistema físico de controlo da plataforma OpenBalance.
- Os parâmetros PID são configuráveis e o código está preparado para testes em tempo real.
- Comentários adicionais no código indicam sugestões de afinação prática (Kp, Ki, Kd).
===============================================================================
*/

#include <Wire.h>
#include <Adafruit_PWMServoDriver.h>  // Biblioteca para controlo do PCA9685 (servos PWM)

// === PARÂMETROS DE CALIBRAÇÃO (definidos com base na montagem física) ===
const int ANG_EQUIL_X  =  90;  // Ângulo neutro para eixo X (posição de equilíbrio)
const int ANG_MIN_X    =  75;  // Ângulo mínimo permitido para o servo X
const int ANG_MAX_X    = 105;  // Ângulo máximo permitido para o servo X

const int ANG_EQUIL_Y  =  77;  // Ângulo neutro para eixo Y
const int ANG_MIN_Y    =  65;  // Ângulo mínimo permitido para o servo Y
const int ANG_MAX_Y    =  95;  // Ângulo máximo permitido para o servo Y

const int PULSE_MIN_US = 1000; // Pulso PWM correspondente ao ângulo mínimo (1 ms)
const int PULSE_MAX_US = 2000; // Pulso PWM correspondente ao ângulo máximo (2 ms)

// === Canais do PCA9685 usados para cada eixo ===
const uint8_t CHANNEL_X = 0;
const uint8_t CHANNEL_Y = 1;
const int PWM_FREQ = 50; // Frequência típica para servos (50 Hz)

// ===== Parâmetros PID por eixo, obtidos pelo método ZN ======
// --------------EIXO X----------------------------------------
const float Kp_X = 0.18, Ki_X = 0.015, Kd_X = 0.07;
// Sugestão: aumenta Kp_X para resposta mais rápida. 
//Se houver oscilações, aumenta Kd_X ou reduz Kp_X.

// --------------EIXO Y----------------------------------------
const float Kp_Y = 0.14, Ki_Y = 0.015, Kd_Y = 0.05;
// Sugestão: se o eixo Y parecer mais lento, 
//testa aumentar Ki_Y para 0.02 ou subir Kp_Y ligeiramente.
// ============================================================

const float SUM_MAX = 300.0;  // Limite para o termo integral
const float D_ALPHA = 0.8;    // Fator de suavização do termo derivativo (filtro exponencial)

// === Variáveis de mapeamento PWM baseadas na calibração ===
int pulseMinX, pulseCenterX, pulseMaxX;
int pulseMinY, pulseCenterY, pulseMaxY;
int PWM_MIN, PWM_MAX;

// === Variáveis de estado PID e controlo ===
float errX = 0, errY = 0;
float prevErrX = 0, prevErrY = 0;
float sumErrX = 0, sumErrY = 0;
float dErrXf = 0, dErrYf = 0;
bool motorsEnabled = false;
unsigned long lastTime = 0;

Adafruit_PWMServoDriver pwm = Adafruit_PWMServoDriver(0x40);
// Instancia o objeto 'pwm' para controlar o módulo PCA9685 no endereço I2C 0x40 (endereço padrão).
// Este driver permite gerar até 16 sinais PWM com resolução de 12 bits, ideal para servos.
// Nota: o endereço pode ser alterado fisicamente no módulo ligando os pinos A0–A5.


void setup() {
  Serial.begin(115200);     // Inicia a comunicação serial com o PC a 115200 bps
  pwm.begin();              // Inicializa o PCA9685 com o endereço I2C definido
  pwm.setPWMFreq(PWM_FREQ); // Define a frequência de operação dos servos (tipicamente 50 Hz)
  delay(10);                // Pequena pausa para estabilização
  
  // Converte os ângulos físicos dos servos em pulsos PWM (em microssegundos)
  pulseMinX    = map(ANG_MIN_X,   ANG_MIN_X, ANG_MAX_X, PULSE_MIN_US, PULSE_MAX_US);
  pulseCenterX = map(ANG_EQUIL_X, ANG_MIN_X, ANG_MAX_X, PULSE_MIN_US, PULSE_MAX_US);
  pulseMaxX    = map(ANG_MAX_X,   ANG_MIN_X, ANG_MAX_X, PULSE_MIN_US, PULSE_MAX_US);

  pulseMinY    = map(ANG_MIN_Y,   ANG_MIN_Y, ANG_MAX_Y, PULSE_MIN_US, PULSE_MAX_US);
  pulseCenterY = map(ANG_EQUIL_Y, ANG_MIN_Y, ANG_MAX_Y, PULSE_MIN_US, PULSE_MAX_US);
  pulseMaxY    = map(ANG_MAX_Y,   ANG_MIN_Y, ANG_MAX_Y, PULSE_MIN_US, PULSE_MAX_US);

  // Converte os limites PWM (em us) para valores entre 0 e 4095 (12 bits do PCA9685)
  int periodUs = 1000000 / PWM_FREQ;                 // Calcula o período em microssegundos
  PWM_MIN = map(PULSE_MIN_US, 0, periodUs, 0, 4095);
  PWM_MAX = map(PULSE_MAX_US, 0, periodUs, 0, 4095);

  // Inicializa os servos nas posições de equilíbrio
  setServoPulse(CHANNEL_X, pulseCenterX);
  setServoPulse(CHANNEL_Y, pulseCenterY);

  lastTime = millis();   // Guarda a marca de tempo inicial para o cálculo do dt no PID
}

void loop() {
  // Lê continuamente a porta serial para receber comandos da dashboard
  while (Serial.available()) {
    String line = Serial.readStringUntil('\n');  // Lê uma linha até encontrar '\n'
    line.trim();                                 // Remove espaços em branco e quebras de linha
    if (line.length() < 1) continue;             // Ignora linhas vazias

    // Comando para ativar os motores
    if (line.startsWith("M1")) {
      motorsEnabled = true;                      // Ativa flag de controlo PID
      Serial.println("MOTORS_ON");               // Resposta opcional para dashboard
    }

    // Comando para desligar motores e reiniciar PID
    else if (line.startsWith("M0")) {
      motorsEnabled = false;                     // Desativa flag
      resetPID();                                // Reinicia todas as variáveis PID
      Serial.println("MOTORS_OFF");              // Confirmação
    }

    // Comando para envio de erros no formato "E,erroX,erroY"
    else if (line.startsWith("E,")) {
      int i1 = line.indexOf(',');
      int i2 = line.indexOf(',', i1 + 1);

      // Verifica se o formato é válido antes de extrair os valores
      if (i1 > 0 && i2 > i1) {
        // Extrai e converte os erros X e Y como floats
        errX = constrain(line.substring(i1+1, i2).toFloat(),
                         -(pulseCenterX - pulseMinX),
                          (pulseMaxX   - pulseCenterX));
        errY = constrain(line.substring(i2+1).toFloat(),
                         -(pulseCenterY - pulseMinY),
                          (pulseMaxY   - pulseCenterY));

        // Aplica PID apenas se os motores estiverem ativados
        if (motorsEnabled) applyPID();
      }
    }

    // Futuras extensões: adicionar comandos para calibração, modo automático, etc.
  }
}


void applyPID() {
  unsigned long now = millis();
  float dt = (now - lastTime) / 1000.0;                           // Tempo decorrido (em segundos)
  lastTime = now;

  if (dt <= 0.001 || dt > 0.5) return;                            // Proteção contra dt inválido (ruído ou pausas longas)

  // --- PID para eixo X ---
  sumErrX += errX * dt;                                           // Atualiza a integral
  sumErrX = constrain(sumErrX, -SUM_MAX, SUM_MAX);                // Limita a integral para evitar wind-up

  float rawDX = (errX - prevErrX) / dt;                           // Derivada bruta
  dErrXf = D_ALPHA * dErrXf + (1 - D_ALPHA) * rawDX;              // Derivada suavizada (filtro exponencial)
  float outX = (Kp_X * errX) + (Ki_X * sumErrX) + (Kd_X * dErrXf);// Saída PID

  prevErrX = errX;                                                // Atualiza erro anterior
  int pulseX = constrain(pulseCenterX + int(outX), pulseMinX, pulseMaxX); // Calcula pulso servo
  setServoPulse(CHANNEL_X, pulseX);                               // Envia comando para servo X

  // --- PID para eixo Y ---
  sumErrY += errY * dt;
  sumErrY = constrain(sumErrY, -SUM_MAX, SUM_MAX);

  float rawDY = (errY - prevErrY) / dt;
  dErrYf = D_ALPHA * dErrYf + (1 - D_ALPHA) * rawDY;
  float outY = (Kp_Y * errY) + (Ki_Y * sumErrY) + (Kd_Y * dErrYf);

  prevErrY = errY;
  int pulseY = constrain(pulseCenterY + int(outY), pulseMinY, pulseMaxY);
  setServoPulse(CHANNEL_Y, pulseY);
}


void resetPID() {
  sumErrX  = 0; sumErrY  = 0;  // Zera integrais
  prevErrX = 0; prevErrY = 0;  // Zera erros anteriores
  dErrXf   = 0; dErrYf   = 0;  // Zera derivadas filtradas
}

void setServoPulse(uint8_t channel, int microseconds) {
  int periodUs = 1000000 / PWM_FREQ;                       // Período total do PWM
  int pwmVal = map(microseconds, 0, periodUs, 0, 4095);    // Mapeia valor para resolução do PCA9685
  pwmVal = constrain(pwmVal, PWM_MIN, PWM_MAX);            // Garante que está dentro dos limites seguros
  pwm.setPWM(channel, 0, pwmVal);                          // Envia o sinal para o canal indicado
}

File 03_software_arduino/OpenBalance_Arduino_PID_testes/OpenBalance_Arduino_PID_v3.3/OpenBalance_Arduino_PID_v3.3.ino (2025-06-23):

#include <Wire.h>
#include <Adafruit_PWMServoDriver.h>
#include <EEPROM.h>

// ================================================
// OpenBalance Arduino – Versão 2.1 (Estável)
// PID e Calibração controlados via Serial
// Adicionada lógica para comando de teste MOVE
// ================================================

// --- PROTOCOLO DE COMUNICAÇÃO (v2.1) ---
// Comandos recebidos da Dashboard (terminados em '\n'):
//   'M1'                 -> Ativa os motores e o controlo PID.
//   'M0'                 -> Desativa os motores e recentra os servos.
//   'E,errX,errY'        -> Recebe o erro (em pixels) e aplica um ciclo PID.
//   'P,kp,ki,kd,kp,ki,kd'-> Define os 6 ganhos PID (X e Y).
//   'CAL_X,min,eq,max'   -> Define os ângulos (graus) de calibração do eixo X.
//   'CAL_Y,min,eq,max'   -> Define os ângulos (graus) de calibração do eixo Y.
//   'MOVE,ch,angle'      -> (NOVO) Move um servo para um ângulo específico para teste.
//   'SAVE'               -> Guarda a calibração e os ganhos PID atuais na EEPROM.
//
// Respostas enviadas para a Dashboard:
//   'ACK: ...', 'INFO: ...', 'WARN: ...'

// --- Estrutura para guardar configurações na EEPROM ---
struct Settings {
  long version; // Usado para validar se a EEPROM tem dados válidos
  float Kp_X, Ki_X, Kd_X;
  float Kp_Y, Ki_Y, Kd_Y;
  int ANG_MIN_X, ANG_EQUIL_X, ANG_MAX_X;
  int ANG_MIN_Y, ANG_EQUIL_Y, ANG_MAX_Y;
};

const long SETTINGS_VERSION = 20240522L; // Mude este número se alterar a struct

// === PARÂMETROS DE HARDWARE ===
const int PULSE_MIN_US = 1000; // Microsegundos para o ângulo mínimo do servo
const int PULSE_MAX_US = 2000; // Microsegundos para o ângulo máximo do servo
const uint8_t CHANNEL_X = 0;
const uint8_t CHANNEL_Y = 1;
const int PWM_FREQ = 50; // Hz

// === PARÂMETROS DE CONTROLO (Valores padrão, podem ser sobrepostos pela EEPROM/Serial) ===
Settings settings = {
  SETTINGS_VERSION,
  // Ganhos PID
  0.25, 0.005, 0.1,  // Kp_X, Ki_X, Kd_X
  0.15, 0.02,  0.1,  // Kp_Y, Ki_Y, Kd_Y
  // Calibração de Ângulos
  75, 89, 105,       // ANG_MIN_X, ANG_EQUIL_X, ANG_MAX_X
  65, 79, 100        // ANG_MIN_Y, ANG_EQUIL_Y, ANG_MAX_Y
};

const float SUM_MAX = 300.0; // Limite Anti-Windup para o termo integral
const float D_ALPHA = 0.8;   // Fator de suavização para o termo derivativo

// ===== Variáveis de estado e cálculo =====
int pulseMinX, pulseCenterX, pulseMaxX;
int pulseMinY, pulseCenterY, pulseMaxY;

float errX = 0, errY = 0;
float prevErrX = 0, prevErrY = 0;
float sumErrX = 0, sumErrY = 0;
float dErrXf = 0, dErrYf = 0; // Derivada filtrada
bool motorsEnabled = false;
unsigned long lastTime = 0;

Adafruit_PWMServoDriver pwm = Adafruit_PWMServoDriver(0x40);

// ==================
// ===    SETUP   ===
// ==================
void setup() {
  Serial.begin(115200);
  pwm.begin();
  pwm.setPWMFreq(PWM_FREQ);
  delay(10);

  loadSettings(); // Tenta carregar configurações da EEPROM
  
  recalculatePulseLimits(); // Calcula os pulsos com base nos ângulos (padrão ou da EEPROM)
  
  // Posiciona os servos no ponto de equilíbrio
  setServoPulse(CHANNEL_X, pulseCenterX);
  setServoPulse(CHANNEL_Y, pulseCenterY);

  lastTime = millis();
}

// =================
// ===    LOOP   ===
// =================
void loop() {
  if (Serial.available()) {
    handleSerialCommand();
  }
}

// ===================================
// === PROCESSAMENTO DOS COMANDOS ===
// ===================================
void handleSerialCommand() {
  String line = Serial.readStringUntil('\n');
  line.trim();
  if (line.length() < 1) return;

  if (line.startsWith("M1")) {
    motorsEnabled = true;
    Serial.println("ACK: MOTORS_ON");
  } 
  else if (line.startsWith("M0")) {
    motorsEnabled = false;
    resetPID();
    setServoPulse(CHANNEL_X, pulseCenterX);
    setServoPulse(CHANNEL_Y, pulseCenterY);
    Serial.println("ACK: MOTORS_OFF");
  } 
  else if (line.startsWith("E,")) {
    if (sscanf(line.c_str(), "E,%f,%f", &errX, &errY) == 2) {
      if (motorsEnabled) applyPID();
    }
  }
  else if (line.startsWith("P,")) {
    if (sscanf(line.c_str(), "P,%f,%f,%f,%f,%f,%f", 
        &settings.Kp_X, &settings.Ki_X, &settings.Kd_X, 
        &settings.Kp_Y, &settings.Ki_Y, &settings.Kd_Y) == 6) {
      Serial.println("ACK: PID gains updated.");
    }
  }
  else if (line.startsWith("CAL_X,")) {
    if (sscanf(line.c_str(), "CAL_X,%d,%d,%d", 
        &settings.ANG_MIN_X, &settings.ANG_EQUIL_X, &settings.ANG_MAX_X) == 3) {
      recalculatePulseLimits();
      Serial.println("ACK: X-axis calibration updated.");
    }
  }
  else if (line.startsWith("CAL_Y,")) {
    if (sscanf(line.c_str(), "CAL_Y,%d,%d,%d", 
        &settings.ANG_MIN_Y, &settings.ANG_EQUIL_Y, &settings.ANG_MAX_Y) == 3) {
      recalculatePulseLimits();
      Serial.println("ACK: Y-axis calibration updated.");
    }
  }
  else if (line.startsWith("SAVE")) {
    saveSettings();
    Serial.println("ACK: Settings saved to EEPROM.");
  }
  // =======================================================
  // === NOVO BLOCO DE CÓDIGO PARA TESTE DE CALIBRAÇÃO ===
  // =======================================================
  else if (line.startsWith("MOVE,")) {
    int channel = -1, angle = -1;
    // Extrai o canal e o ângulo do comando
    if (sscanf(line.c_str(), "MOVE,%d,%d", &channel, &angle) == 2) {
      if (channel >= 0 && channel <= 1 && angle >= 0 && angle <= 180) {
        // Converte o ângulo recebido (0-180) para um pulso em microssegundos
        int pulse_us = map(angle, 0, 180, PULSE_MIN_US, PULSE_MAX_US);
        
        // Usa a nossa função segura para mover o servo
        setServoPulse(channel, pulse_us);
        
        // Envia feedback de volta para a dashboard
        Serial.print("ACK: Moved channel ");
        Serial.print(channel);
        Serial.print(" to angle ");
        Serial.println(angle);
      }
    }
  }
}

// ===================================
// === LÓGICA DE CONTROLO E SERVOS ===
// ===================================

void applyPID() {
  unsigned long now = millis();
  float dt = (now - lastTime) / 1000.0;
  lastTime = now;
  if (dt <= 0.001) return;

  // Eixo X
  sumErrX += settings.Ki_X * errX * dt;
  sumErrX = constrain(sumErrX, -SUM_MAX, SUM_MAX);
  float dErrX = (errX - prevErrX) / dt;
  dErrXf = D_ALPHA * dErrXf + (1 - D_ALPHA) * dErrX;
  float outX = (settings.Kp_X * errX) + sumErrX + (settings.Kd_X * dErrXf);
  prevErrX = errX;
  int pulseX = constrain(pulseCenterX + int(outX), pulseMinX, pulseMaxX);
  setServoPulse(CHANNEL_X, pulseX);

  // Eixo Y
  sumErrY += settings.Ki_Y * errY * dt;
  sumErrY = constrain(sumErrY, -SUM_MAX, SUM_MAX);
  float dErrY = (errY - prevErrY) / dt;
  dErrYf = D_ALPHA * dErrYf + (1 - D_ALPHA) * dErrY;
  float outY = (settings.Kp_Y * errY) + sumErrY + (settings.Kd_Y * dErrYf);
  prevErrY = errY;
  int pulseY = constrain(pulseCenterY + int(outY), pulseMinY, pulseMaxY);
  setServoPulse(CHANNEL_Y, pulseY);
}

void resetPID() {
  sumErrX = 0; sumErrY = 0;
  prevErrX = 0; prevErrY = 0;
  dErrXf = 0; dErrYf = 0;
}
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

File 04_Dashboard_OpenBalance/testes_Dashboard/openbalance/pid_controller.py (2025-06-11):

# --------------------------------------------------
# File: pid_controller.py
# --------------------------------------------------
class PIDController:
    def __init__(self, Kp: float, Ki: float, Kd: float, setpoint: float = 0):
        self.Kp = Kp
        self.Ki = Ki
        self.Kd = Kd
        self.setpoint = setpoint
        self._last_error = 0
        self._integral = 0

    def update(self, process_variable: float) -> float:
        error = self.setpoint - process_variable
        self._integral += error
        derivative = error - self._last_error
        self._last_error = error
        return self.Kp * error + self.Ki * self._integral + self.Kd * derivative

    def set_gains(self, Kp: float, Ki: float, Kd: float):
        self.Kp, self.Ki, self.Kd = Kp, Ki, Kd
        self._integral = 0
        self._last_error = 0

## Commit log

2025-06-09 Atulizaçao
    [2 Eixos BALL suporte.stl, Eixo Central Ball Balancer.stl, Suporte uniao camara OpenBalance.stl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]
2025-06-11 dashboard e arduino
2025-06-23 OpenBalance v1.0
    [Calibracao_ZN_22_maio_2025.xlsx]
